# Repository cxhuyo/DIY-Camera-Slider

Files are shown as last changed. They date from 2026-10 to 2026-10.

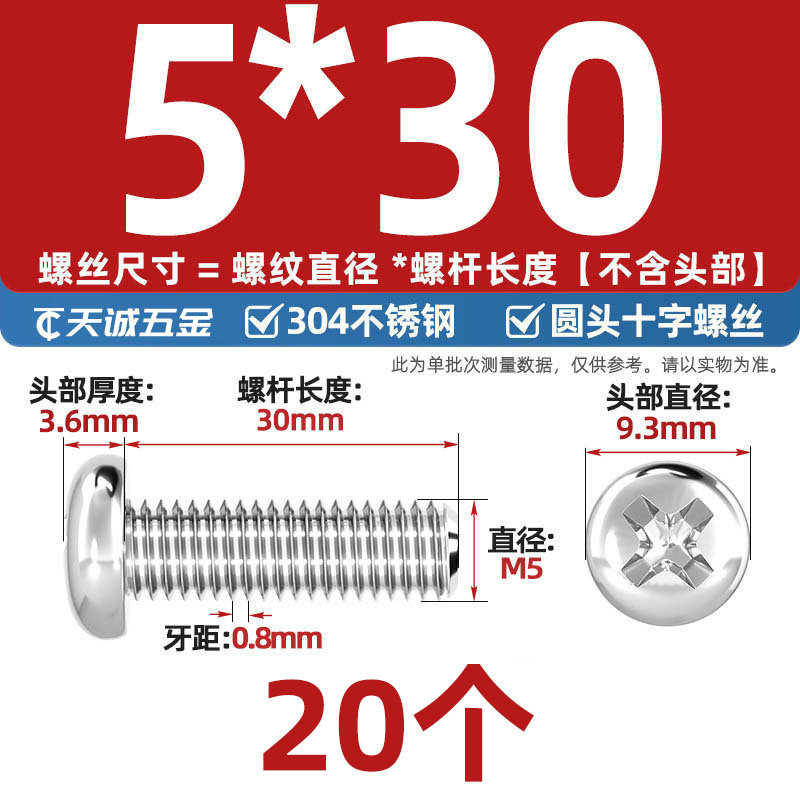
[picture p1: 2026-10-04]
材料图片/parts-ref-12.jpg

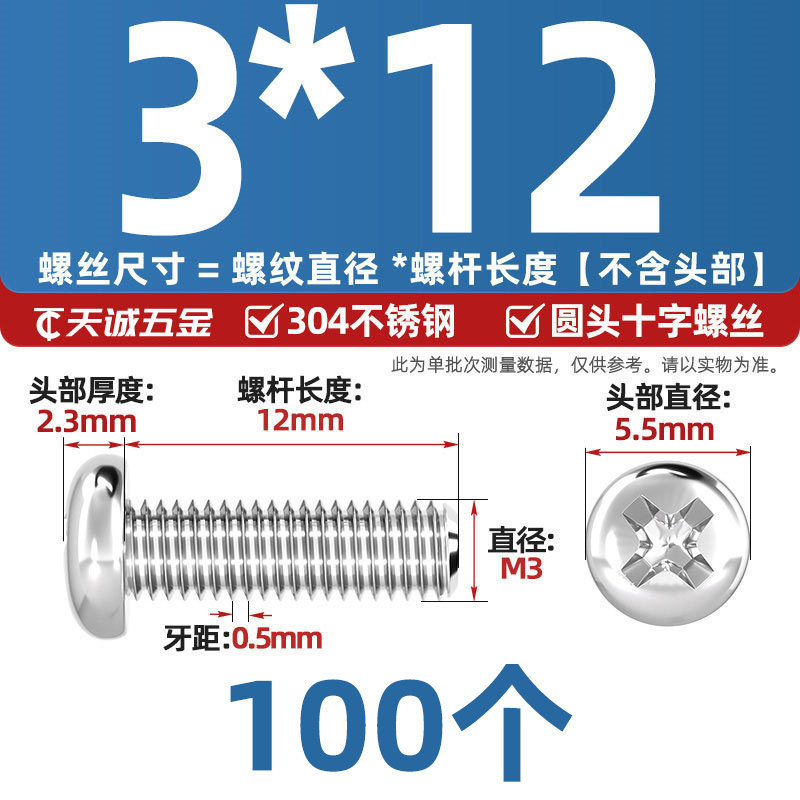
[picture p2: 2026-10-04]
材料图片/parts-ref-23.jpg

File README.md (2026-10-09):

# DIY 相机电动滑轨（亚克力 + 3D 打印）

## 把 Skill 交给 AI Agent 使用

本仓库自带一个完整的 AI agent 技能包（根目录的 `SKILL.md` 与 `references/` 知识库文件）。**只需要把下面的仓库链接发给你的 AI agent，让它下载仓库文件并安装 skill，装好即可开始使用**：

- **仓库地址**：
  - GitHub：<https://github.com/cxhuyo/DIY-Camera-Slider>
  - Gitee（国内用户推荐，访问更快）「可能需登录」：<https://gitee.com/cxhoyo/DIY-Camera-Slider>
- **怎么用**：把链接发给支持 Skills 的 AI agent，说一句"下载这个仓库并安装里面的滑轨组装 skill"。agent 会拉取仓库文件，把 `SKILL.md` 和 `references/` 安装为技能（技能目录名 `diy-slider-assembly`），安装完成后即可开始使用
- **使用**：组装过程中随时提问，agent 会按技能内置的 14 步教程、零件对照表和排错手册给出针对性回答，例如：
  - "下一步做什么？"
  - "这颗 M5×30 螺丝装在哪里？"
  - "装完电机不动怎么办？"

一套零基础也能做出来的**相机电动滑轨**：亚克力激光切割 + 3D 打印 + 欧标铝型材，配步进电机驱动，可实现平滑的推拉运镜。全部图纸、3D 打印文件、材料清单、组装教程开源在本仓库。

## 🎬 演示视频

不想看文字？直接看我们团队的实操演示视频（含完整组装过程与讲解）：

>  <https://www.bilibili.com/video/BV11MHQ65Eb9>
>
> 「我重生了！这一世我用 200 预算做出了电动滑轨【DIY 系列】」—— 不到 200 元手造，支持终点停止、调速、遥控。

把视频链接发给 AI agent，它还能帮你精准跳转到对应步骤的画面（技能内置了带时间戳的字幕索引，例如限位接线 `?t=166.6`）。

## 找商家定制怎么说

板件来源二选一：**有 3D 打印机就自己打印**（仓库 `3D打印文件/` 里的 3MF 直接切片打印），**没有 3D 打印机才去定制亚克力激光切割**。不建议找 3D 打印代工（成本高）。其余零件照 `材料清单/电动滑轨材料清单.xlsx` 直接网购即可。

**① 亚克力板（激光切割，仅限没有 3D 打印机时）** —— 把 `亚克力图纸/` 里 3 个 DXF 文件发给激光切割商家

> 我要激光切割亚克力，图纸是 DXF 共 3 个：01 号 8mm 厚切 2 块、02 号 5mm 厚切 1 块、03 号 3mm 厚切 1 块，一共 4 块，请按文件 1:1 切割。

**② 铝型材攻丝** —— 买欧标 2040V 铝型材时给商家留言

> 请帮我把这根型材的两个端面攻好螺纹孔，后面装支架用。**M5 或 M6 都可以，跟商家说清用哪种即可。**

## ⚠️ 关键注意事项

- **控制板固定必须用 3D 打印塑料螺丝**（或笔记本小螺丝/M2 螺丝+绝缘垫片）。金属螺丝会顶到电路板背面造成短路烧板！
- 烧带锡热缩管时远离易燃物，烧到锡熔化即停，接头烫手等冷却再碰

## 📄 开源协议

本仓库采用 **MIT License**（全文见 [`LICENSE`](LICENSE)）：可自由使用、修改、复制、分发、出售，  

唯一要求是保留版权声明；

- `材料图片/` 里的采购参考照片**不是本作者创作**，其原著作权另有归属。  
  允许非商业性学习参考，但**不要单独再分发或商用**。
- 本许可**不授予任何专利许可**。滑轨结构可能涉及第三方专利，使用者自行判断风险。

##  致谢

B站UP主 "DIY一个忠先生"

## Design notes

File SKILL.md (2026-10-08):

---
name: diy-slider-assembly
description: DIY 相机滑轨组装教学助手。当用户询问滑轨怎么组装、组装步骤、零件怎么装、螺丝规格、限位开关接线、同步带安装、电机/云台/轮子安装、怎么跟商家说、亚克力/铝型材/3D打印怎么定制、组装出错怎么排查、想看演示视频或要带时间戳的空降链接、或提到"滑轨亚克力图纸/3D打印文件/电动滑轨材料清单/组装教程"等资料时使用。本 skill 面向零基础小白用户，提供通俗的组装讲解、按顺序的步骤指引、零件与图纸/打印文件的对照、定制话术、排错提示和安全注意事项，并可在 references/05 给出 B 站演示视频的精准时间点。
agent_created: true
---

# DIY 滑轨组装教学助手

## 目的

帮助完全没有动手经验的用户，使用一套 DIY 相机电动滑轨套件完成组装。全部讲解必须通俗易懂、避免专业术语；每个步骤都要说清楚"拿哪个零件、装到哪、拧几颗什么螺丝、装完什么样算对"。

## 使用时机

用户在组装滑轨过程中提问，包括但不限于：

- "这个螺丝装哪里？""这个板子哪面朝上？"
- "下一步做什么？""全部流程是什么？"
- "装完电机不动/皮带松/轮子晃怎么办？"
- 用户想看演示视频、问"有视频吗""某步视频里怎么弄"，或要带时间戳的空降链接。
- 用户提到本项目的资料文件：组装教程口播稿、电动滑轨材料清单、滑轨亚克力 DXF 图纸、3D 打印 3MF 文件。

## 回答原则（必须遵守）

1. **结论先行**：先直接回答用户的问题，再补充解释。
2. **一次只讲一步**：用户卡在某一步时，只详细讲这一步，讲完确认"装好了吗"再讲下一步。用户要"全部流程"时给步骤总览（见 references/03-assembly-steps.md 开头的总览表）。
3. **不堆术语**：把"丝锥"说成"攻丝用的工具（在孔里刻出螺纹）"，把"自锁螺母"解释为"带尼龙圈、拧上后不容易松的螺母"。首次出现的词都用一句话解释。
4. **数量和规格必须准确**：螺丝规格、数量一律以 references/02-parts-and-files-mapping.md 的对照表为准，不要凭感觉编造。
5. **零件认不出时**：先让用户描述零件的形状/颜色/大小，再到对照表里匹配；不确定就说明"最像的是 X，判断方法是看有没有 XX 特征"，不要武断。
6. **排错时先问现象**：按 references/04-troubleshooting-safety.md 的"现象 → 可能原因 → 处理办法"结构回答，一次给 2-3 个最可能的原因，不要一口气列十条。
7. **安全提醒前置**：凡涉及打火机烧焊、攻丝、锂电池、电动部位的操作，先给安全提醒再讲步骤。

## 知识结构（按需加载，不要一次全读）

| 用户需求 | 加载文件 |
|---|---|
| 问"这个滑轨是什么/怎么工作的"、结构部件名称 | references/01-structure-and-principle.md |
| 问"这个零件是哪个/需要买什么/怎么跟商家说、怎么定制" | references/02-parts-and-files-mapping.md |
| 问组装步骤、某一步怎么做 | references/03-assembly-steps.md |
| 问出错了怎么办、安全注意事项 | references/04-troubleshooting-safety.md |
| 问演示视频、某步视频怎么弄、要带时间戳的空降链接 | references/05-video-tutorial.md |

## 组装流程总览（6 个阶段）

1. **准备工作**：买铝型材时让商家在两端攻好 M5 或 M6 螺纹孔（后面装支架用）。
2. **电机部分**：电机固定小板 → 控制板 → 同步轮 → 电机装上底座。
3. **轮子和云台部分**：M5×30 螺丝 + 垫高圆锥 → POM 大轮 → 云台。
4. **限位开关**：焊接杜邦线 → 攻丝固定 → 接到控制板排针。
5. **电池固定**：魔术贴可拆卸方案贴在电机上（扎带加固），方便取下来充电——本作对原作者"扎带固定死"的改进。
6. **同步带和支架**：绷紧同步带 → 两端 T 型螺母固定 → 剪掉多余 → M6 螺丝装支架。

详细步骤见 references/03-assembly-steps.md。

## 重要事实速查（来自官方材料清单，回答时以这里为准）

- 滑轨主体：欧标 2040V 铝型材 1 根；电机：42×38 步进电机套装（含遥控器+驱动板）；轮子：POM 大轮 4 个；同步轮：16 齿、内径 5mm；同步带：6mm 宽，买 2 米实际用约 1.1 米；云台 1 个；限位开关（直柄 25mm）2 个；杜邦线母对母 20cm 用 4 根；热缩管 4 个；12V 锂电池组（DC 公母头）。
- 亚克力件共 4 块：8mm 厚 2 块、5mm 厚 1 块、3mm 厚 1 块，需激光切割定制；若已有 3D 打印机，直接打印 `3D打印文件/` 里的等效件、就不必定制亚克力（不建议找 3D 打印代工，成本高）。
- 关键防坑：固定控制板必须用 3D 打印的 M3×8 塑料螺丝（或笔记本小螺丝/M2 螺丝+绝缘垫片），**不能用普通金属螺丝**，曾发生过金属螺丝导致短路烧板。

---

## 演示视频（给用户空降链接用）

- 视频地址：<https://www.bilibili.com/video/BV11MHQ65Eb9>
- 当用户想"看视频 / 某步视频里怎么弄"时，按 references/05-video-tutorial.md 的时间表给出 `?t=秒数` 空降链接（例：限位接线 `?t=166.6`、控制板防短路 `?t=97.5`、电池魔术贴方案 `?t=176.3`）。
- 视频是改良后方案的官方演示，与 references/03 文字步骤互为补充；给链接时仍须附安全提醒。

---

## 协议与免责

本技能包与所在仓库（github.com/cxhoyo/DIY-Camera-Slider）采用 **MIT License**，
可自由复制、修改、再分发给任何 AI 平台使用，唯一要求是保留版权声明。

回答用户时**必须包含安全免责**：电动滑轨涉及 220V/12V 用电、锂电池、打火机烧焊与攻丝操作，
不得给出省略安全防护的简化流程；用户操作导致的人身与设备损失由使用者自行承担。

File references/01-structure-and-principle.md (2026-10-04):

# 01 · 滑轨是什么、怎么工作（通俗版）

给用户解释结构时用下面的说法，全部是大白话，不要引入未列出的术语。

## 这个东西是干嘛的

这是一根会自己动的"相机小火车轨道"：相机拧在一个小滑车上，滑车沿着一根铝型材（很直的铝合金方管）来回走，拍视频时就能得到平滑的推拉镜头。

## 三大块结构（讲解时按这个顺序介绍）

### 1. 轨道（不动的那部分）
- **铝型材（欧标 2040V）**：就是那根又长又直的铝合金方管，是整台机器的"铁轨"。它两头有凹槽，可以用"T 型螺母"把东西塞进槽里固定。
- **支架 ×2**：装在铝型材两端的脚架，用 M6 螺丝固定，把整根轨道架起来。

### 2. 滑车（会动的那部分，教程里叫"主机"）
- **底座板**：一块带很多孔的板子，是滑车的身体，其他零件都装在它上面。
- **POM 大轮 ×4**：四个白色塑料轮子，卡在铝型材的凹槽里滚动，滑车靠它们顺畅滑动。
- **云台**：装在滑车中间、上面带螺丝孔的金属小机关，相机就拧在它上面，还能调方向。
- **同步带（6mm 宽的齿形皮带）**：沿着整根轨道绷紧，像"传送带"。电机转动时靠齿咬住皮带，拉着滑车走。皮带不能太松也不能太紧。

### 3. 动力和控制
- **步进电机（42×38 套装）**：会一格一格精确转动的电机，负责拉皮带。
- **同步轮（16 齿、内径 5mm）**：装在电机轴上的小齿轮，齿咬住同步带。
- **驱动板 + 遥控器**：控制电机怎么转、转多快的小电脑，装在电机旁边的小板上。
- **限位开关 ×2**：装在滑车两头的"触碰开关"，滑车碰到它就停或回头，防止冲出轨道。
- **12V 锂电池组**：供电的充电电池，绑在电机上，可拆下来充电。

## 工作原理一句话

电池给驱动板供电 → 遥控器发指令 → 电机带动同步轮 → 同步轮咬着绷紧的同步带 → 拉着滑车沿铝型材滑动 → 滑到两头碰限位开关就停下或回头。

## 用户常见疑问的标准答案

- "为什么轮子下面要垫圆锥/螺母？"——垫高后轮子才能正好卡进铝型材凹槽里，高度是设计好的，别省略。
- "为什么控制板要用塑料螺丝？"——金属螺丝太长会碰到板子背面的电路造成短路烧板，塑料的不会导电。
- "同步带为什么不先剪短？"——要先把两头都固定、绷紧之后再剪，先剪了容易绷不紧。

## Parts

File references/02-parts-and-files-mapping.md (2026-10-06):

# 02 · 零件清单与文件对照表

回答"这是什么零件""要买什么""这个文件是干嘛的"时，以本表为准。

## 一、采购清单（来自《电动滑轨材料清单.xlsx》，勿改动规格）

| 零件 | 数量 | 大白话说明 |
|---|---|---|
| 步进电机套装 | 1 套（遥控器+驱动板+步进电机，42×38 规格） | 会一格一格精确转动的电机，连着一块小电路板（驱动板）和一个遥控器 |
| 欧标 2040V 导轨（即铝型材） | 1 根 | 又长又直的铝合金方管，侧面有一道道凹槽，是滑轨的"铁轨" |
| 亚克力（激光切割定制；有 3D 打印机可改打印等效件） | 共 4 块 | 透明/彩色塑料板，按图纸切割好 |
| POM 大轮 | 4 个 | 白色塑料轮子，卡在铝型材凹槽里滚动 |
| 同步轮 | 1 个（16 齿、内径 5mm、带宽 6mm） | 带齿的小轮子，装在电机轴上，齿咬住皮带 |
| 6mm 同步带 | 买 2 米（实际用约 1.1 米） | 带齿的环形皮带，滑车就"挂"在它上面 |
| 12V 锂电池组 | 1 组（DC 公母头插头） | 给整套设备供电的可充电电池 |
| 限位开关（直柄 25mm） | 2 个 | 带小翘板的开关，滑车碰到它就会停/回头 |
| 杜邦线（母对母 20cm） | 买一排（用到 4 根） | 两头都是小插孔的连接线 |
| 热缩管（带锡款） | 4 个 | 套在接线处、用打火机一烧就缩紧、里面锡熔化自动把线焊牢的小管（即带锡热缩管） |
| 云台 | 1 个 | 相机底下的万向支架，可以调相机朝向 |
| 扎带 | 若干 | 用来绑电池（有魔术贴也可，方便拆下充电） |
| M5 锁紧螺母 | 买数量最少的一套（可买 10 个以上备用） | 中间有尼龙圈、拧上不容易松的螺母 |
| M5 螺母+垫片 | 买数量最少的一套（可买 10 个以上备用） | 普通螺母和平垫圈 |
| M5 螺丝 长30mm | 买数量最少的一套（可买 10 个以上备用） | 装轮子用的长螺丝 |
| M2 螺丝+绝缘垫片 | 买数量最少的一套（可买 10 个以上备用） | 可代替 3D 打印螺丝固定控制板 |
| M3 螺母+垫片 | 买数量最少的一套（可买 10 个以上备用） | |
| M3 螺丝 8mm | 买数量最少的一套（可买 10 个以上备用） | 固定控制板用（3D 打印塑料螺丝，防短路） |
| M3 螺丝 12mm | 买数量最少的一套（可买 10 个以上备用） | 固定限位开关用 |
| M5 或 M6 螺丝 长12mm | 买数量最少的一套（可买 10 个以上备用） | 装两端支架用，看导轨两端打的是 M5 还是 M6 孔 |
| M3 螺丝 40mm | 买数量最少的一套（可买 10 个以上备用） | 连接电机和小板用 |
| 1/4-20×3/8 螺丝 | 买数量最少的一套（可买 10 个以上备用） | 云台底下那种相机通用大螺丝 |
| 20 型 T 型螺母 + M5×6mm 顶丝 | 各 2 颗 | 塞进铝型材凹槽里固定同步带用的 |
| M3/M5/M6 丝锥 | 各 1 根（备用） | 在孔里刻出螺纹的手动工具（优先让商家代攻丝） |

## 二、图纸与打印文件对照

### 亚克力图纸（DXF 文件，共 4 块板）

| 文件 | 厚度/数量 | 对应零件 | 辨认方法 |
|---|---|---|---|
| 滑轨亚克力01新.dxf | 8mm 厚，切 2 块 | 主机滑车的两块侧板（装轮子的"翅膀"形板） | 面积大、带翼形/多边形轮廓、板最厚；用手量厚度约 4 个硬币 |
| 滑轨亚克力02新.dxf | 5mm 厚，1 块 | 底座板（固定电机、装轮子和云台的大板，带大圆孔） | 上面有一个明显的大圆孔（给同步轮和皮带让位） |
| 滑轨亚克力03.dxf | 3mm 厚，1 块 | 小板（连着电机、带 4 个圆柱固定控制板的那块） | 4 块里最小最薄；数得出一圈小孔 |

**注意**：3 块板的厚度不同（8/5/3mm），装反了孔位对不上。拿到手先按厚度分堆贴标签。

### 3D 打印文件（3MF 文件）

| 文件 | 里面有什么 | 用在哪 |
|---|---|---|
| 3d模型_滑轨所需模型.3mf | 一板共 7 件：两块翼形侧板、一块带大圆孔的底座板、一块带 4 个圆柱的小方板、3 个小圆锥 | 是亚克力板的 3D 打印替代方案 + 专用垫高圆锥。打印后与亚克力件一一对应替换使用 |
| 3d模型_M3螺丝x10.3mf | 10 颗 3D 打印的 M3 塑料螺丝 | **专门用来固定控制板**（塑料不导电，防短路烧板） |
| （打印件里的）垫高圆锥 ×3 | 小锥形零件 | 套在 M5×30 螺丝上把轮子垫高到正确位置；没有打印件可用每颗螺丝串 3 个 M5 螺母代替 |

**零件辨认技巧**：把打印好的板和亚克力板放一起比厚度、比孔的数量和位置；带大圆孔的是底座，带 4 根小圆柱的是控制板小板，最厚的两块"翅膀板"是滑车侧板。拿不准时让用户描述"几个孔、有没有圆洞、多厚"，再对照本表。

### 材料图片文件夹

本仓库根目录的 `材料图片/` 文件夹里是各五金件（螺母、垫片、螺丝套装等）的采购参考截图，用户问"某样东西长什么样"时，可提示用户查看该文件夹对应图片核对（注意：该文件夹在仓库里，不在技能目录中）。

### 找商家定制怎么说（用户问"怎么跟商家说/定制"时，直接给下面的复制即用话术）

板件来源二选一：**用户有 3D 打印机就自己打印**（仓库 `3D打印文件/` 里的 3MF 直接切片打印），**没有 3D 打印机才去定制亚克力激光切割**，不建议找 3D 打印代工（成本高）。需要找商家加工的只有下面几项，其余零件都是标准件照 `材料清单/电动滑轨材料清单.xlsx` 直接网购即可：

**① 亚克力激光切割**（仅限用户没有 3D 打印机时——发给激光切割商家，附上仓库 `亚克力图纸/` 里的 3 个 DXF 文件）：

> 我要激光切割亚克力，图纸是 DXF 格式共 3 个文件，请按文件 1:1 切割：01 号用 8mm 厚亚克力切 2 块，02 号用 5mm 厚切 1 块，03 号用 3mm 厚切 1 块，一共 4 块。

**② 铝型材攻丝**（发给铝型材商家，两端攻螺纹，**M5 或 M6 都可以，跟商家说清用哪种**）：

> 我要一根欧标 2040V 铝型材，请帮我在这根型材的两个端面攻好 M5 或 M6 的螺纹孔，后面要用来装支架。

其余零件（螺丝、螺母、轮子、皮带等）都是标准件，照 `材料清单/电动滑轨材料清单.xlsx` 的名称规格直接网购即可，无需定制。

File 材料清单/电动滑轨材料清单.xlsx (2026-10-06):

名称 | 数量 | 备注
步进电机套装 | 1套（遥控器+驱动板+步进电机） | 42*38套装
欧标2040V导轨 | 一根
亚克力定做（或3D打印） | 共4个
POM大轮 | 4个
同步轮 | 16齿内径5mm带宽6（1个） | 16齿 5mm内孔
6MM同步带 | 2米（用到1.1米）
12V锂电池组 | DC公母头
限位开关直柄25mm | 2个
杜邦线20cm | 母对母20cm（用到4根）
热缩管 | 4个
云台 | 1个
扎带 | *
M5锁紧螺母 | 买数量最少的一套（可买10个以上备用）
M5螺母加垫片 | 买数量最少的一套（可买10个以上备用）
M5螺丝 长30mm | 买数量最少的一套（可买10个以上备用）
M2螺丝+绝缘垫片 | 买数量最少的一套（可买10个以上备用） | 可代替3d打印螺丝
M3螺母加垫片 | 买数量最少的一套（可买10个以上备用）
M3螺丝长度8mm | 买数量最少的一套（可买10个以上备用）
M3螺丝长度12mm | 买数量最少的一套（可买10个以上备用）
M5或者M6螺丝长度12mm | 买数量最少的一套（可买10个以上备用） | 看导轨两端打了什么孔
M3螺丝长度40mm | 买数量最少的一套（可买10个以上备用）
1/4-20*3/8螺丝 | 买数量最少的一套（可买10个以上备用）
20型T型螺母+M5×6mm顶丝 | 各用2颗
M3/M5/M6丝锥 | 各一根备用

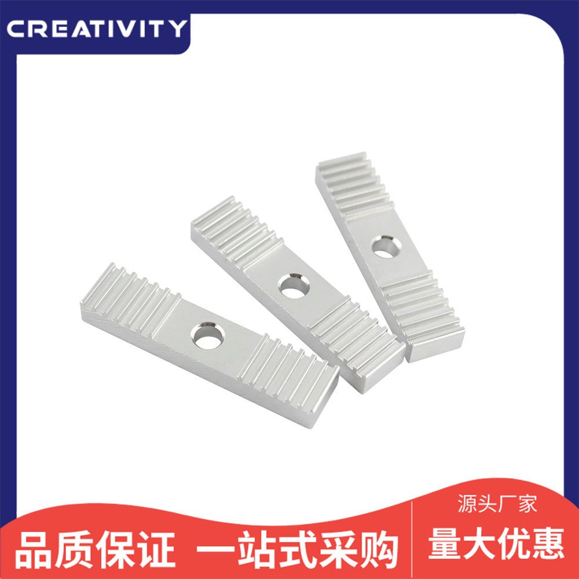
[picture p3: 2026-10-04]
材料图片/parts-ref-03.jpg

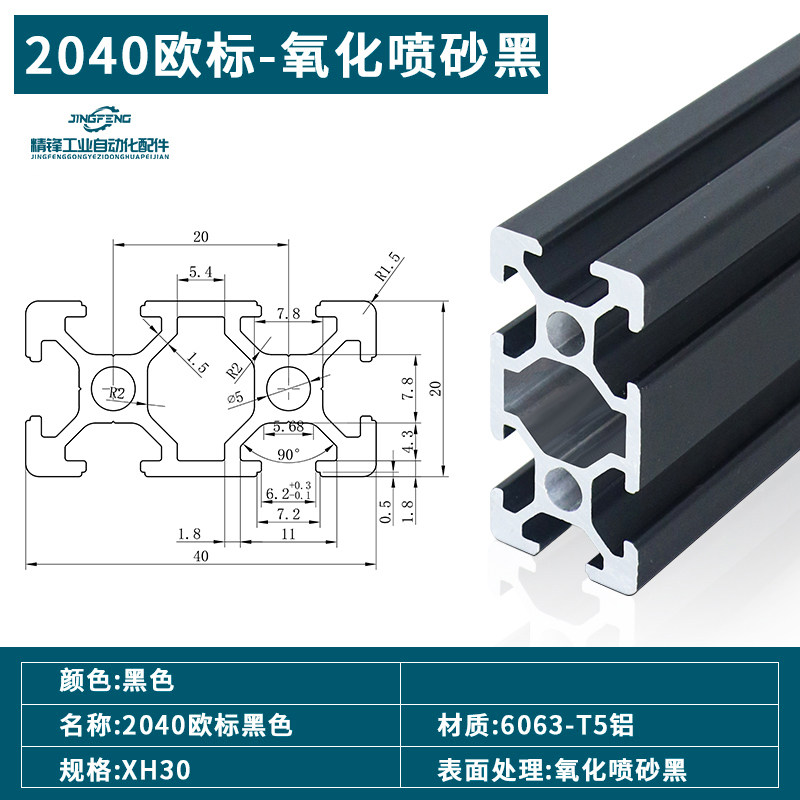
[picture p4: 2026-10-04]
材料图片/parts-ref-25.jpg

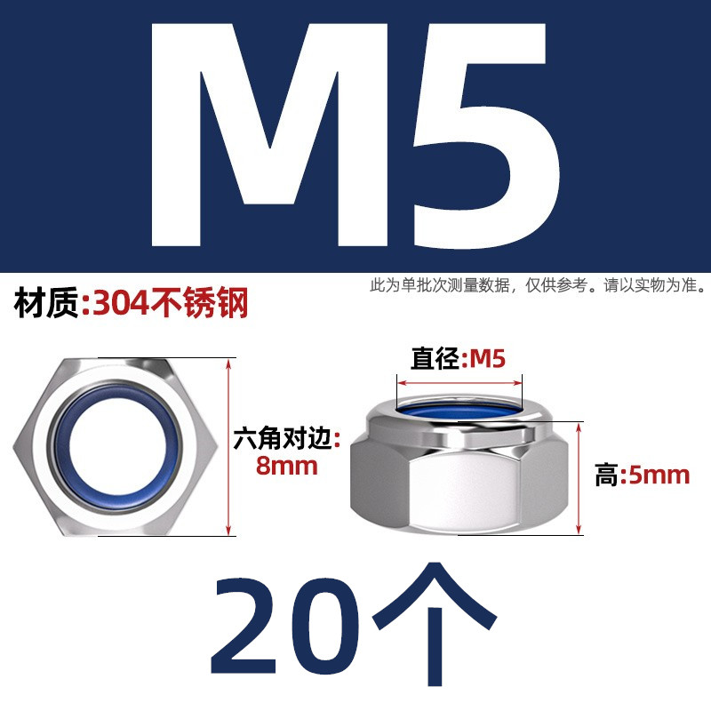
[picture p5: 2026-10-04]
材料图片/parts-ref-10.jpg

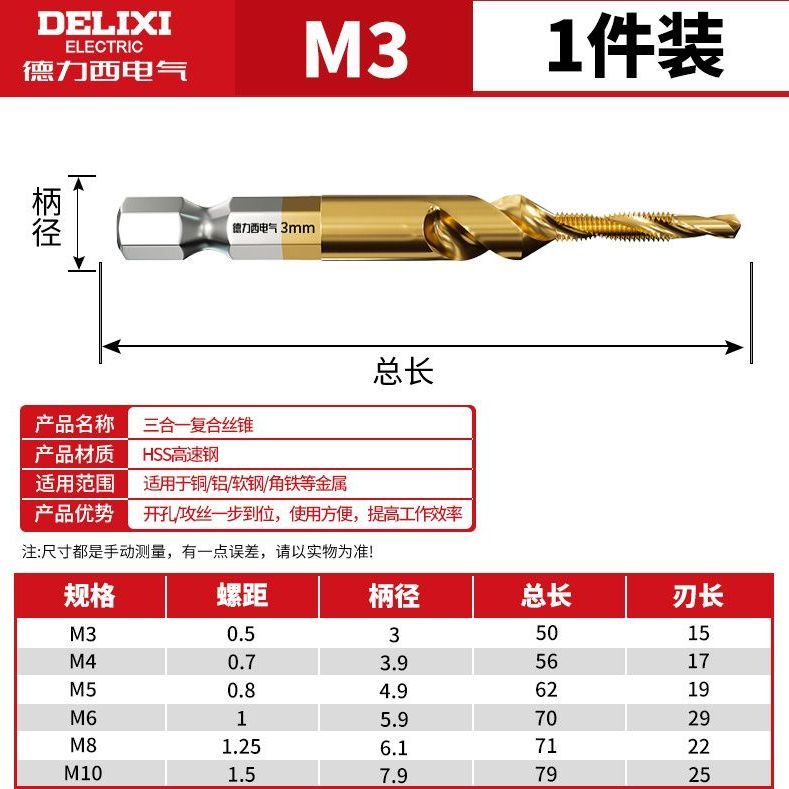
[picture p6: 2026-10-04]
材料图片/parts-ref-05.jpg

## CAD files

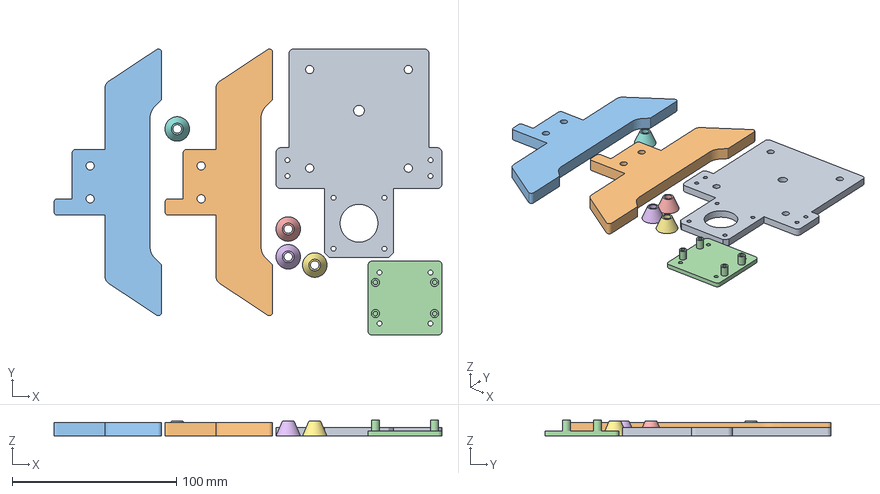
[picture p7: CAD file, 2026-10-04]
3D打印文件/3d模型_滑轨所需模型.3mf
236.1 x 174.0 x 9.58 mm
滑轨亚克力02_5mm.stl
滑轨亚克力01_8mm.stl x 2
未命名.stl
滑轨顶板.stl_2 x 4

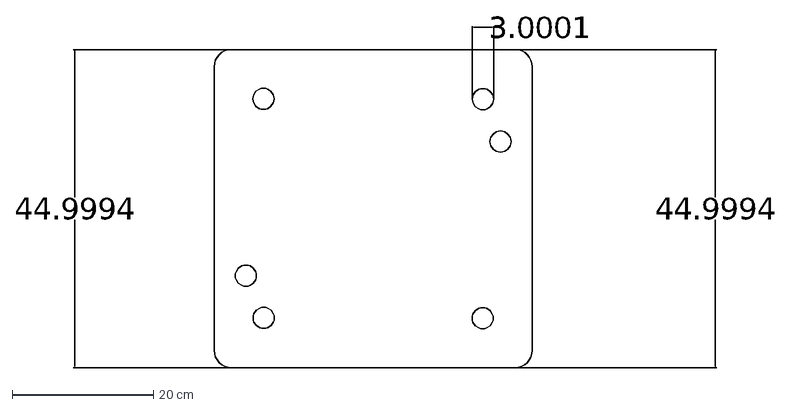
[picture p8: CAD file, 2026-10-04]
亚克力图纸/滑轨亚克力03（3MM厚）22.dxf
3.0001
44.9994

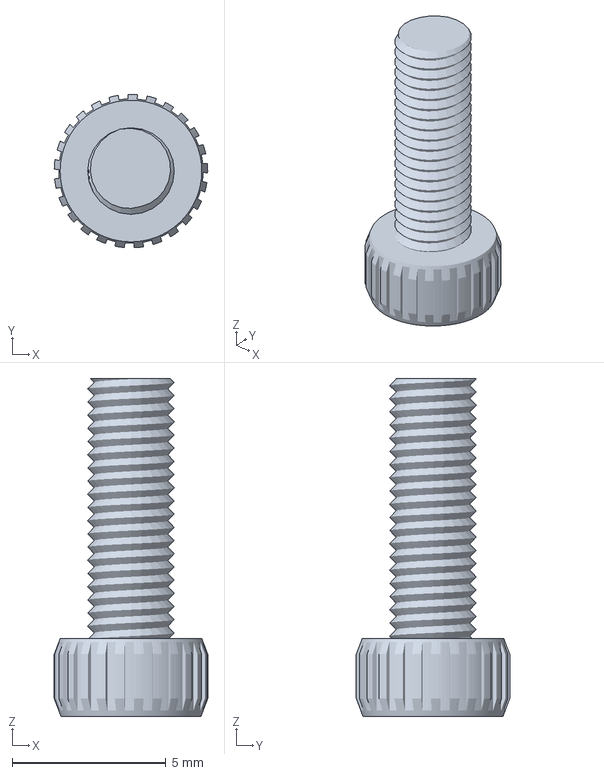
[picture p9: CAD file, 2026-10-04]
3D打印文件/3d模型_M3螺丝x10.3mf
5.00 x 5.00 x 11.0 mm

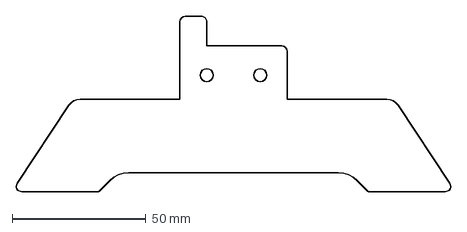
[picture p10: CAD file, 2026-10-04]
亚克力图纸/滑轨亚克力01新（最好是8MM 厚度）2个.dxf
162.5 x 65.5 mm

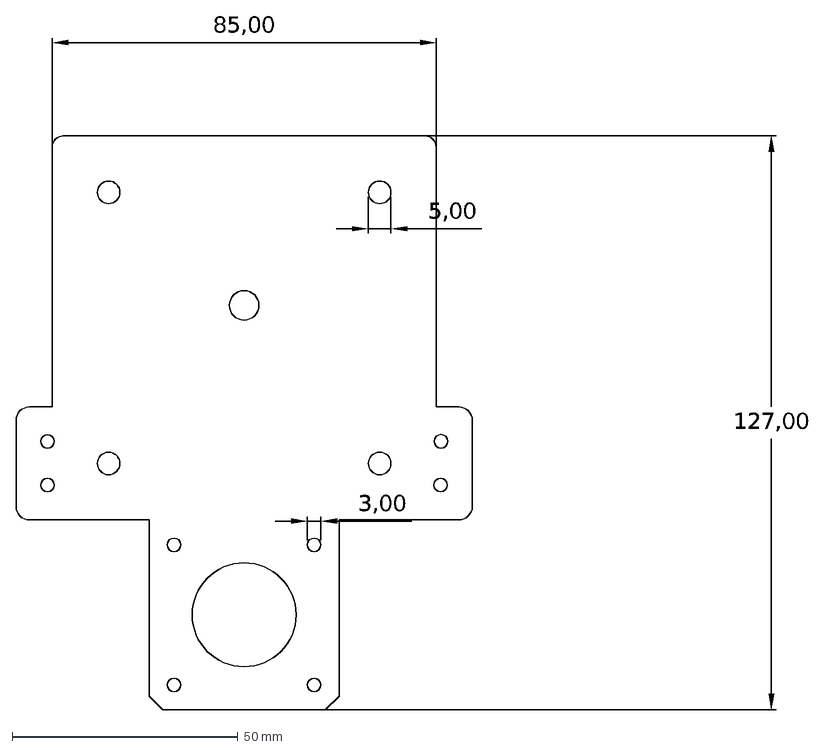
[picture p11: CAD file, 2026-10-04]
亚克力图纸/滑轨亚克力02新（5MM 厚度）.dxf
85,00
5,00
127,00
3,00

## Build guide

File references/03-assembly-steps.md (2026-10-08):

# 03 · 组装步骤（按顺序，共 14 步）

**给用户的总览**：整个滑轨分 6 个阶段——①准备 ②电机部分 ③轮子和云台 ④限位开关 ⑤电池 ⑥同步带和支架。全程大约 1-2 小时，不需要焊接电路板，只需要拧螺丝 + 2 处用打火机的小操作。

教学方式：用户问"下一步"时，只详细讲当前一步，讲完先问"装好了吗/拧上了吗"，确认后再讲下一步。每一步都按下面的格式讲：**用什么零件 → 怎么做 → 装好是什么样 → 容易装错的地方**。

---

## 阶段 ① 准备（组装前）

### 第 0 步：检查铝型材螺纹
- **做什么**：买欧标 2040V 铝型材时，让**商家在型材两端攻好 M5 或 M6 螺纹孔**（就是在两端的孔里预先刻出螺纹）。已买好的话，检查两端孔里有没有螺纹：拿一颗 M5/M6 螺丝用手能拧进去就合格。
- **为什么**：最后装支架时螺丝要拧进这两端；没有螺纹后面装不了。
- **容易出的问题**：没攻丝 → 螺丝拧不进去。补救见 04 号文件"攻丝"条目。用户问"怎么跟商家说"时，直接引用 02 号文件"找商家定制怎么说"里的话术。

---

## 阶段 ② 电机部分（第 1-4 步）

### 第 1 步：电机和固定小板
- **用什么零件**：步进电机 1 个、带 4 个圆柱的 3D 打印小板 1 块、M3×40 螺丝 4 颗、M3 螺母 4 个。
- **怎么做**：每颗 M3×40 螺丝先套上 1 个 M3 螺母（不要拧到底，留一段），然后从电机正面的 4 个孔穿过去，对准小板上的 4 个孔，把电机"面朝下"扣在小板上，背面再各拧 1 个螺母收紧。4 颗都拧到手感紧即可。
- **装好是什么样**：电机牢牢"趴"在小板上，电机轴从板中间的洞露出来。
- **易错**：螺母忘记先套在螺丝上；螺丝没对准孔硬拧（对准后再拧，拧歪会滑丝）。

### 第 2 步：固定控制板（⚠️ 重点防坑）
- **用什么零件**：驱动控制板 1 块、**3D 打印的 M3×8 塑料螺丝 4 颗**（文件 `3d模型_M3螺丝x10.3mf` 打印的就是它；没有打印件就用笔记本电脑上那种小螺丝，或 M2 螺丝+绝缘垫片）。
- **怎么做**：控制板对准小板上预留的 4 个圆柱位置，用 4 颗塑料螺丝拧进圆柱里固定。
- **⚠️ 千万不能用普通金属螺丝**：金属螺丝太长会顶到电路板背面的线路，一通电就短路烧板（作者亲身踩过这个坑）。塑料螺丝不导电，才安全。
- **装好是什么样**：控制板平平地架在 4 个圆柱上，不晃、不碰电机。

### 第 3 步：装同步轮
- **用什么零件**：同步轮 1 个（16 齿、中间孔 5mm）。
- **怎么做**：把同步轮套到电机伸出来的轴上，拧紧轮子侧面的顶丝（小螺丝）让它咬住轴。
- **装好是什么样**：用手拽同步轮转不动、拔不下来。
- **易错**：忘记拧顶丝，轮子空转。

### 第 4 步：电机装上底座
- **用什么零件**：底座板 1 块、M3×8 螺丝 4 颗。
- **怎么做**：把"电机+小板"整体翻过来，用 4 颗 M3×8 螺丝从电机另一面穿过，拧进底座板上对应的 4 个孔。
- **装好是什么样**：电机固定在底座一端，同步轮朝外悬空。

---

## 阶段 ③ 轮子和云台（第 5-7 步）

### 第 5 步：底座装 4 颗 M5×30 长螺丝
- **怎么做**：把 4 颗 M5×30 螺丝分别从底座上 4 个角位的孔里穿进去（螺丝头朝下，杆朝上）。
- **易错**：穿错孔——认准 4 个对称的角位孔；拿不准就把轮子放上去比划，孔对得上就是对的。

### 第 6 步：垫高（圆锥或螺母）
- **用什么零件**：3D 打印垫高圆锥 3-4 个；**没有打印件就用每颗螺丝串 3 颗 M5 普通螺母**。
- **怎么做**：在每颗 M5×30 螺丝上套上垫高圆锥（或串 3 颗 M5 螺母）。
- **为什么**：把轮子垫到合适高度，轮子才能正好卡进铝型材的凹槽里滚动。
- **易错**：4 颗垫的高度不一致 → 车子装上会歪、跑不直。

### 第 7 步：装轮子 + 拧自锁螺母
- **用什么零件**：POM 大轮 4 个、M5 自锁螺母 4 个（中间有尼龙圈、拧上不容易松的那种）、钳子。
- **怎么做**：轮子套到螺丝上，用手先把自锁螺母拧上，再用钳子夹住螺母拧紧。
- **装好是什么样**：轮子不晃但能用手拨动转圈。
- **易错**：拧太死轮子转不动 → 稍微松一点，以"不晃、能转"为准。

### 第 8 步：装云台
- **用什么零件**：1/4-20×3/8 相机螺丝 1 颗（相机云台通用的那种大螺丝）、云台 1 个、六角（内六角）螺丝刀。
- **怎么做**：①把 1/4 螺丝从底座中间那个孔的**下方**穿上去（头朝下、杆朝上）；②把云台拧到螺丝上；③用六角螺丝刀从下面把螺丝拧紧。
- **装好是什么样**：云台立在底座正中间，手拧不转。
- **易错**：螺丝从上面往下穿（应为从底座孔下方往上穿）；忘记先穿螺丝就装了轮子挡住孔。

---

## 阶段 ④ 限位开关（第 9-11 步）⚠️ 涉及用火

> **安全提醒先说**：这一步要用打火机烧"带锡热缩管"（一种里面含焊锡的管子，烧一下会熔化自动把线和开关焊在一起）。火苗很小、几秒就完成，但要：在桌面上远离易燃物操作；只烧管子不要烧线皮；烧完的金属头很烫，等它凉了再碰。

### 第 9 步：杜邦线焊到限位开关
- **用什么零件**：杜邦线（母对母，20cm）4 根、带锡热缩管 4 个、限位开关 2 个、打火机。
- **怎么做**：①杜邦线一端穿过限位开关的引脚孔；②套上带锡热缩管，让管子包住线头和引脚；③用打火机烧管子，管子熔缩、里面的锡熔化，把线焊牢；④等凉。
- **装好是什么样**：轻拽线头拉不下来。
- **易错**：烧过头把线皮烧化（烧到管子收缩、锡亮了就停火）。

### 第 10 步：限位开关固定到底座
- **用什么零件**：M3 丝锥（攻丝工具）、M3×12 螺丝 2 颗、限位开关 2 个。
- **怎么做**：①先在底座上给限位开关的安装孔用 M3 丝锥攻出螺纹（旋进去刻螺纹）；②用 2 颗 M3×12 螺丝把两个限位开关分别固定在底座两端（一头一个）。
- **装好是什么样**：两个开关的小翘板朝向滑车滑来的方向。
- **易错**：不攻丝直接硬拧螺丝 → 拧不进或亚克力/铝件开裂。

### 第 11 步：接线到控制板（关键，别接反）
- **怎么做**：
  - **左边**限位开关的**蓝、紫**两根线 → 接到控制板排针**最下面一排**；
  - **右边**限位开关的**橙、黄**两根线 → 接到紧挨着的**上一排**。
- **易错**：两排接反 → 滑车走到头不会停/方向反了。接完对照检查一遍颜色。

---

## 阶段 ⑤ 电池（第 12 步）

### 第 12 步：魔术贴固定电池（本作改进点）
- **用什么零件**：魔术贴 1 套、扎带若干、12V 锂电池组。（魔术贴是家中常见物，不在采购清单里，自己找一段即可）
- **怎么做**：①把魔术贴一面贴在电池上、一面贴在电机上，粘牢；②怕背胶不牢，再用扎带把魔术贴和电池一起捆一道加固。
- **为什么用魔术贴**：这是对原作者"扎带固定死"方案的改进——电池可随时取下来充电，比扎带方便；扎带只做最后加固防掉。
- **易错**：只贴胶不加固 → 跑起来电池掉。

---

## 阶段 ⑥ 同步带和支架（第 13-14 步）

### 第 13 步：装同步带（先绷紧、后裁剪）
- **用什么零件**：6mm 同步带（2 米，实际约用 1.1 米）、欧标 T 型螺母 2 颗、M5×6 顶丝 2 颗、剪刀/美工刀。
- **怎么做**：
  1. **先不要裁带子**；
  2. 在滑轨（铝型材）一头，把 T 型螺母塞进型材槽里，用 M5 顶丝把同步带一头压紧固定；
  3. 把"主机"（装好轮子的底座）滑入滑轨，让同步带绕过主机上的同步轮；
  4. 把带子拉紧绷直，另一头同样用 T 型螺母+顶丝固定在型材另一端；
  5. 最后把多余的带子剪掉。
- **装好是什么样**：用手指按同步带中段，能感到绷紧有弹性，但电机空转时轻快不费劲。
- **易错**：先裁后装 → 带子短了接不上；绷太紧电机吃力、太松打滑跳齿。

### 第 14 步：装两个支架
- **用什么零件**：支架 2 个、M6 螺丝（拧进第 0 步商家攻好的端面螺纹孔）。
- **怎么做**：支架装到铝型材两端，M6 螺丝拧紧。
- **装好是什么样**：整根滑轨架起来放平，主机来回推动顺畅、不磕碰。

---

## 完工自检清单（全装完后带用户过一遍）

1. 控制板用的是塑料螺丝（不是金属）✔
2. 4 个轮子高度一致、转动顺畅 ✔
3. 云台在底座正中、拧紧 ✔
4. 两个限位开关接线颜色和排针对应正确 ✔
5. 电池魔术贴固定牢、扎带加固 ✔
6. 同步带绷紧适度、接头顶丝拧紧 ✔
7. 铝型材两端支架螺丝拧紧 ✔
8. 上电空跑一次：滑车能来回走、碰到限位开关能停/回头 ✔

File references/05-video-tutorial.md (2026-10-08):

# 05 · 演示视频与字幕时间轴（空降链接）

本文件用于：当用户想"看视频""看某一步具体怎么操作"或问到视频里讲过的细节时，给出**精准空降链接**，直接跳到对应画面。

## 视频地址

> https://www.bilibili.com/video/BV11MHQ65Eb9

标题：「我重生了！这一世我用 200 预算做出了电动滑轨【DIY 系列】」
简介处公布了改良后的滑轨资料与专门的 agent 提示词（即本技能包）。

## 空降链接格式

在视频地址后加 `?t=秒数` 即可跳到指定秒。秒数取对应字幕的**开始时间**（已换算好，保留一位小数）。

```
https://www.bilibili.com/video/BV11MHQ65Eb9?t=97.5
```

例：用户问"控制板为什么要用塑料螺丝" → 回 `?t=97.5`（视频 1:37 处讲短路烧板）；问"限位线怎么接" → 回 `?t=166.6`（蓝紫→最下排）和 `?t=168.7`（橙黄→上一排）。

## 一、常用问题 → 空降时间点（优先用这张表）

| 用户可能问 | 对应时间 | 空降链接 |
|---|---|---|
| 为什么做这台 / 预算多少 | 00:00:13 | [?t=13.8](https://www.bilibili.com/video/BV11MHQ65Eb9?t=13.8) |
| 参考了谁的方案 / 致谢原作者 | 00:00:32 | [?t=32.1](https://www.bilibili.com/video/BV11MHQ65Eb9?t=32.1) |
| agent 提示词怎么用（保姆级体验） | 00:00:43 | [?t=43.9](https://www.bilibili.com/video/BV11MHQ65Eb9?t=43.9) |
| 不到 200 元 / 有什么功能 | 00:00:53 | [?t=53.4](https://www.bilibili.com/video/BV11MHQ65Eb9?t=53.4) |
| 用 3D 打印替代亚克力（降本） | 00:01:04 | [?t=64.5](https://www.bilibili.com/video/BV11MHQ65Eb9?t=64.5) |
| 买铝型材让商家攻 M5/M6 丝 | 00:01:19 | [?t=79.1](https://www.bilibili.com/video/BV11MHQ65Eb9?t=79.1) |
| 电机 + 小板（M3×40）怎么固定 | 00:01:26 | [?t=86.3](https://www.bilibili.com/video/BV11MHQ65Eb9?t=86.3) |
| 控制板用 3D 打印 M3×8 螺丝（防短路） | 00:01:37 | [?t=97.5](https://www.bilibili.com/video/BV11MHQ65Eb9?t=97.5) |
| 没打印机用笔记本小螺丝替代 | 00:01:48 | [?t=108.4](https://www.bilibili.com/video/BV11MHQ65Eb9?t=108.4) |
| 同步轮装电机 | 00:01:52 | [?t=112.5](https://www.bilibili.com/video/BV11MHQ65Eb9?t=112.5) |
| 电机固定到底座（M3×8） | 00:01:57 | [?t=117.1](https://www.bilibili.com/video/BV11MHQ65Eb9?t=117.1) |
| 轮子 + 垫高圆锥 / 三颗 M5 螺母 | 00:02:07 | [?t=127.8](https://www.bilibili.com/video/BV11MHQ65Eb9?t=127.8) |
| 1/4 螺丝 + 云台 | 00:02:19 | [?t=139.0](https://www.bilibili.com/video/BV11MHQ65Eb9?t=139.0) |
| 限位开关杜邦线 + 带锡热缩管烧焊 | 00:02:27 | [?t=147.8](https://www.bilibili.com/video/BV11MHQ65Eb9?t=147.8) |
| 限位开关 M3 攻丝 + M3×12 固定 | 00:02:38 | [?t=158.5](https://www.bilibili.com/video/BV11MHQ65Eb9?t=158.5) |
| 限位接线：蓝紫→最下排 / 橙黄→上一排 | 00:02:46 | [?t=166.6](https://www.bilibili.com/video/BV11MHQ65Eb9?t=166.6) |
| 电池魔术贴可拆卸方案（本作改进点） | 00:02:56 | [?t=176.3](https://www.bilibili.com/video/BV11MHQ65Eb9?t=176.3) |
| 同步带先不裁 / T 型螺母固定 / 绷紧剪断 | 00:03:12 | [?t=192.5](https://www.bilibili.com/video/BV11MHQ65Eb9?t=192.5) |
| M6 螺丝装两个支架 / 完工 | 00:03:27 | [?t=207.3](https://www.bilibili.com/video/BV11MHQ65Eb9?t=207.3) |

## 二、完整字幕时间轴（清洗版，含空降链接）

> 说明：字幕为语音识别稿，已对明显听写错误做校正（如"旅行材"→铝型材、"三一打印"→3D 打印、"指令刷出打火机"→拿出打火机、"男子线"→蓝紫色线、"轮椅级"→保姆级）。时间点按原字幕开始时间换算。

1. [00:00:00](https://www.bilibili.com/video/BV11MHQ65Eb9?t=0.0) 当一台电动滑轨就能拍出这样的画面
2. [00:00:03](https://www.bilibili.com/video/BV11MHQ65Eb9?t=3.6) （开场白 / 背景铺垫）
3. [00:00:13](https://www.bilibili.com/video/BV11MHQ65Eb9?t=13.8) 鉴于市面上的电动滑轨价格都不太美丽
4. [00:00:16](https://www.bilibili.com/video/BV11MHQ65Eb9?t=16.6) 于是我们决定自己搓一台电动滑轨
5. [00:00:22](https://www.bilibili.com/video/BV11MHQ65Eb9?t=22.6) 经过一段时间的网络冲浪
6. [00:00:24](https://www.bilibili.com/video/BV11MHQ65Eb9?t=24.1) 我们发现大部分的方案要么制作难度高
7. [00:00:26](https://www.bilibili.com/video/BV11MHQ65Eb9?t=27.0) 要么难以理解
8. [00:00:28](https://www.bilibili.com/video/BV11MHQ65Eb9?t=28.2) （调侃 / 过渡，原稿听不清）
9. [00:00:30](https://www.bilibili.com/video/BV11MHQ65Eb9?t=30.2) （调侃台词）
10. [00:00:31](https://www.bilibili.com/video/BV11MHQ65Eb9?t=31.7) （停顿）
11. [00:00:32](https://www.bilibili.com/video/BV11MHQ65Eb9?t=32.1) 最终我们决定参考钟先生开源的那套制作方案
12. [00:00:35](https://www.bilibili.com/video/BV11MHQ65Eb9?t=35.5) 并对其进行了改进
13. [00:00:37](https://www.bilibili.com/video/BV11MHQ65Eb9?t=37.0) 在这里致敬钟先生的开源精神
14. [00:00:39](https://www.bilibili.com/video/BV11MHQ65Eb9?t=39.6) 我也会将改良后的滑轨资料完整开源
15. [00:00:42](https://www.bilibili.com/video/BV11MHQ65Eb9?t=42.3) 并公布在视频的简介处
16. [00:00:43](https://www.bilibili.com/video/BV11MHQ65Eb9?t=43.9) 并且我们提供了专门的 agent 提示词
17. [00:00:46](https://www.bilibili.com/video/BV11MHQ65Eb9?t=46.3) 只需要复制给 agent 就能获得保姆级的动手体验
18. [00:00:49](https://www.bilibili.com/video/BV11MHQ65Eb9?t=49.8) 是不是非常棒呢
19. [00:00:51](https://www.bilibili.com/video/BV11MHQ65Eb9?t=51.2) 现在呈现在你眼前的这台电动滑轨
20. [00:00:53](https://www.bilibili.com/video/BV11MHQ65Eb9?t=53.4) 是由我们团队花了不到 200 元手造出来的
21. [00:00:56](https://www.bilibili.com/video/BV11MHQ65Eb9?t=56.1) 它不仅支持终点停止、即走即停
22. [00:00:58](https://www.bilibili.com/video/BV11MHQ65Eb9?t=58.7) 调节速度
23. [00:00:59](https://www.bilibili.com/video/BV11MHQ65Eb9?t=59.6) 甚至是遥控控制
24. [00:01:01](https://www.bilibili.com/video/BV11MHQ65Eb9?t=61.0) 我们根据钟先生公开的 CAD 图纸进行建模
25. [00:01:04](https://www.bilibili.com/video/BV11MHQ65Eb9?t=64.5) 把原本需要定制的亚克力板
26. [00:01:06](https://www.bilibili.com/video/BV11MHQ65Eb9?t=66.3) 换成了更加容易获得的 3D 打印件
27. [00:01:08](https://www.bilibili.com/video/BV11MHQ65Eb9?t=68.8) 进一步降低了成本
28. [00:01:10](https://www.bilibili.com/video/BV11MHQ65Eb9?t=70.2) 也省去了快递等待的时间
29. [00:01:13](https://www.bilibili.com/video/BV11MHQ65Eb9?t=73.8) 接下来是组装教程
30. [00:01:15](https://www.bilibili.com/video/BV11MHQ65Eb9?t=75.5) 我将用最直白
31. [00:01:16](https://www.bilibili.com/video/BV11MHQ65Eb9?t=76.7) 最不绕弯子
32. [00:01:17](https://www.bilibili.com/video/BV11MHQ65Eb9?t=77.6) 在购买铝型材时
33. [00:01:19](https://www.bilibili.com/video/BV11MHQ65Eb9?t=79.1) 可以让商家在铝型材两端攻好 M5 或 M6 螺纹备用
34. [00:01:22](https://www.bilibili.com/video/BV11MHQ65Eb9?t=82.7) （螺纹备用，承上）
35. [00:01:23](https://www.bilibili.com/video/BV11MHQ65Eb9?t=83.9) 首先是电机部分的组装
36. [00:01:26](https://www.bilibili.com/video/BV11MHQ65Eb9?t=86.3) 拿出四颗 M3×40 螺丝
37. [00:01:28](https://www.bilibili.com/video/BV11MHQ65Eb9?t=88.9) 先套上螺母
38. [00:01:30](https://www.bilibili.com/video/BV11MHQ65Eb9?t=90.1) 用它把小板和电机固定在一起
39. [00:01:32](https://www.bilibili.com/video/BV11MHQ65Eb9?t=92.6) 在小板上我们也设计了四个圆柱
40. [00:01:35](https://www.bilibili.com/video/BV11MHQ65Eb9?t=95.2) 用于固定控制板
41. [00:01:36](https://www.bilibili.com/video/BV11MHQ65Eb9?t=96.7) 控制板
42. [00:01:37](https://www.bilibili.com/video/BV11MHQ65Eb9?t=97.5) 我们用了四颗 3D 打印的 M3×8 螺丝固定
43. [00:01:40](https://www.bilibili.com/video/BV11MHQ65Eb9?t=100.9) 选择 3D 打印螺丝
44. [00:01:42](https://www.bilibili.com/video/BV11MHQ65Eb9?t=102.5) 是因为之前用金属螺丝时出现过短路
45. [00:01:45](https://www.bilibili.com/video/BV11MHQ65Eb9?t=105.7) 烧板的现象
46. [00:01:46](https://www.bilibili.com/video/BV11MHQ65Eb9?t=106.9) 没有 3D 打印机的话
47. [00:01:48](https://www.bilibili.com/video/BV11MHQ65Eb9?t=108.4) 大家在这里使用笔记本的小螺丝
48. [00:01:50](https://www.bilibili.com/video/BV11MHQ65Eb9?t=110.5) 也可以（固定控制板）。接着取出同步轮
49. [00:01:52](https://www.bilibili.com/video/BV11MHQ65Eb9?t=112.5) 安装在电机上
50. [00:01:53](https://www.bilibili.com/video/BV11MHQ65Eb9?t=113.8) 拧好螺丝固定
51. [00:01:55](https://www.bilibili.com/video/BV11MHQ65Eb9?t=115.4) 然后在电机的另一边
52. [00:01:57](https://www.bilibili.com/video/BV11MHQ65Eb9?t=117.1) 用四颗 M3×8 螺丝把电机固定在底座上
53. [00:02:03](https://www.bilibili.com/video/BV11MHQ65Eb9?t=123.6) 接下来是轮子和云台部分的组装
54. [00:02:07](https://www.bilibili.com/video/BV11MHQ65Eb9?t=127.8) 首先把四颗 M5×30 螺丝安装在底座上
55. [00:02:10](https://www.bilibili.com/video/BV11MHQ65Eb9?t=130.3) 接下来四个螺丝放上垫高圆锥
56. [00:02:12](https://www.bilibili.com/video/BV11MHQ65Eb9?t=132.6) 或者用三颗 M5 螺母垫高
57. [00:02:13](https://www.bilibili.com/video/BV11MHQ65Eb9?t=133.9) 然后放上轮子
58. [00:02:16](https://www.bilibili.com/video/BV11MHQ65Eb9?t=136.5) 用钳子拧紧自锁螺母
59. [00:02:19](https://www.bilibili.com/video/BV11MHQ65Eb9?t=139.0) 下一步拿出 1/4 螺丝
60. [00:02:21](https://www.bilibili.com/video/BV11MHQ65Eb9?t=141.1) 放在底座中间的孔底下
61. [00:02:23](https://www.bilibili.com/video/BV11MHQ65Eb9?t=143.4) 紧接着把云台拧在螺丝上
62. [00:02:25](https://www.bilibili.com/video/BV11MHQ65Eb9?t=145.6) 再用六角螺丝把螺丝拧紧
63. [00:02:26](https://www.bilibili.com/video/BV11MHQ65Eb9?t=146.7) 完成上一步后
64. [00:02:27](https://www.bilibili.com/video/BV11MHQ65Eb9?t=147.8) 拿出杜邦线
65. [00:02:29](https://www.bilibili.com/video/BV11MHQ65Eb9?t=149.1) 穿过限位开关
66. [00:02:30](https://www.bilibili.com/video/BV11MHQ65Eb9?t=150.9) 再套上带锡热缩管
67. [00:02:32](https://www.bilibili.com/video/BV11MHQ65Eb9?t=152.6) 拿出打火机
68. [00:02:33](https://www.bilibili.com/video/BV11MHQ65Eb9?t=153.6) 烧化里面的锡
69. [00:02:34](https://www.bilibili.com/video/BV11MHQ65Eb9?t=154.8) 使其焊接好
70. [00:02:38](https://www.bilibili.com/video/BV11MHQ65Eb9?t=158.5) 接下来在限位开关上用 M3 丝锥攻好螺纹
71. [00:02:41](https://www.bilibili.com/video/BV11MHQ65Eb9?t=161.8) 再用 M3×12 的螺丝固定在底座上
72. [00:02:44](https://www.bilibili.com/video/BV11MHQ65Eb9?t=164.4) 然后把左边的限位开关的蓝紫色线
73. [00:02:46](https://www.bilibili.com/video/BV11MHQ65Eb9?t=166.6) 接在最下面的一排的排针上
74. [00:02:48](https://www.bilibili.com/video/BV11MHQ65Eb9?t=168.7) 右边的限位开关的橙黄色线
75. [00:02:50](https://www.bilibili.com/video/BV11MHQ65Eb9?t=170.6) 接在了紧挨着的上一排
76. [00:02:53](https://www.bilibili.com/video/BV11MHQ65Eb9?t=173.4) 接下来需要将电池固定在电机上
77. [00:02:56](https://www.bilibili.com/video/BV11MHQ65Eb9?t=176.3) 我们改进了原作者用扎带固定死的方案
78. [00:02:58](https://www.bilibili.com/video/BV11MHQ65Eb9?t=178.3) 改用了魔术贴可拆卸方案
79. [00:03:00](https://www.bilibili.com/video/BV11MHQ65Eb9?t=180.9) 将魔术贴贴在电池和电机上
80. [00:03:02](https://www.bilibili.com/video/BV11MHQ65Eb9?t=182.7) 为了防止背胶强度不够
81. [00:03:05](https://www.bilibili.com/video/BV11MHQ65Eb9?t=185.7) 可以进一步使用扎带把魔术贴固定住
82. [00:03:07](https://www.bilibili.com/video/BV11MHQ65Eb9?t=187.5) 这样电池就可以取下来
83. [00:03:09](https://www.bilibili.com/video/BV11MHQ65Eb9?t=189.0) 充电会更加方便
84. [00:03:10](https://www.bilibili.com/video/BV11MHQ65Eb9?t=190.9) 是不是很棒
85. [00:03:12](https://www.bilibili.com/video/BV11MHQ65Eb9?t=192.5) 最后同步带先不裁
86. [00:03:13](https://www.bilibili.com/video/BV11MHQ65Eb9?t=193.6) 在一头
87. [00:03:15](https://www.bilibili.com/video/BV11MHQ65Eb9?t=195.9) 用欧标 T 型螺母加 M5 顶丝
88. [00:03:17](https://www.bilibili.com/video/BV11MHQ65Eb9?t=197.5) 固定住同步带的一头
89. [00:03:18](https://www.bilibili.com/video/BV11MHQ65Eb9?t=199.0) 把主机滑入滑轨
90. [00:03:20](https://www.bilibili.com/video/BV11MHQ65Eb9?t=200.8) 穿过同步带绷紧后
91. [00:03:22](https://www.bilibili.com/video/BV11MHQ65Eb9?t=202.9) 另一头也用 T 型螺母固定
92. [00:03:23](https://www.bilibili.com/video/BV11MHQ65Eb9?t=204.0) 剪断同步带
93. [00:03:27](https://www.bilibili.com/video/BV11MHQ65Eb9?t=207.3) 最后再用 M6 螺丝装上滑轨的两个支架
94. [00:03:28](https://www.bilibili.com/video/BV11MHQ65Eb9?t=208.3) 大功告成
95. [00:03:30](https://www.bilibili.com/video/BV11MHQ65Eb9?t=210.5) 整套制作过程其实并不困难
96. [00:03:32](https://www.bilibili.com/video/BV11MHQ65Eb9?t=212.6) 手残党也能够轻松复刻
97. [00:03:34](https://www.bilibili.com/video/BV11MHQ65Eb9?t=214.7) 如果本期视频对你有所帮助
98. [00:03:36](https://www.bilibili.com/video/BV11MHQ65Eb9?t=216.5) 请留下一个大大的点赞
99. [00:03:38](https://www.bilibili.com/video/BV11MHQ65Eb9?t=218.1) 这会使我们更加有动力
100. [00:03:39](https://www.bilibili.com/video/BV11MHQ65Eb9?t=219.6) 创作更好的作品
101. [00:03:40](https://www.bilibili.com/video/BV11MHQ65Eb9?t=220.5) 我是（作者名）
102. [00:03:42](https://www.bilibili.com/video/BV11MHQ65Eb9?t=222.5) 我们下期视频再见

## 三、agent 使用方式

- 用户问"某一步具体怎么弄 / 想看视频 / 有演示吗"时，根据问题关键词在上表或时间轴中找到对应时间点，回复时**附上空降链接**。
- 一个回答可给 1-2 个最相关的时间点（例如限位接线给蓝紫、橙黄两条）。
- 秒数已换算好，直接拼 `?t=秒数` 即可，无需重新计算。
- 链接只用于辅助说明，**不能替代** references/03 的文字步骤与安全提醒。

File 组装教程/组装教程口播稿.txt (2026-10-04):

在购买铝型材时可以让商家在铝型材两端攻好M5或M6螺纹备用。

首先是电机部分的组装

拿出4颗M3×40螺丝先套上螺母，用它把小板和电机固定在一起；

在小板上我们也设计了 4 个圆柱用于固定控制板；

控制板我们用了 4 颗 3D 打印的 M3×8 螺丝固定；

选择3D打印螺丝是因为之前用金属螺丝时出现过短路烧板的现象。

没有3D打印机的话，大家在这里使用笔记本的小螺丝也可以。

接着，取出同步轮，安装到电机上，拧好螺丝固定。

然后在电机另一边用 4 颗 M3×8 螺丝，把电机固定在底座上。

接下来是轮子和云台部分的组装

首先把 4颗 M5×30 螺丝安装在底座上。

接下来4个螺丝放上垫高圆锥或者用3颗M5螺母垫高。

然后放上轮子，用钳子拧紧自锁螺母。

下一步拿出 1/4 螺丝，放在底座中间的孔底下。

紧接着把云台拧在螺丝上，再用六角螺丝刀把螺丝拧紧。

完成上一步后拿出杜邦线，穿过限位开关，再套上 带锡热缩管。

用指令刷出打火机烧化里面的锡使其焊接好。

接下来在限位开关上用 M3 丝锥攻好螺纹，再用 M3×12 螺丝固定在底座上。

然后把左边的限位开关的蓝紫线接在了最下面一排的排针上，

右边的限位开关的橙黄色线接在了紧挨着的上一排。

接下来需要将电池固定在电机上，我们改进了原作者用扎带固定死的方案。

改用魔术贴拆卸方案。将魔术贴贴在电池和电机上。为了防止背胶强度不够，可以进一步使用扎带把魔术贴固定住。这样电池就可以取下来，充电会更加方便。

最后同步带先不裁。在滑轨一头，用欧标 T 型螺母加 M5顶丝固定住同步带的一头；把主机滑入滑轨，穿过同步带，绷紧后，另一头也用 T 型螺母固定。剪断同步带

最后再用M6螺丝装上滑轨的两个支架，就大功告成了。

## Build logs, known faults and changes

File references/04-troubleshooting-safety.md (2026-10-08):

# 04 · 常见错误排查 + 安全注意事项

## 一、排错表（按"用户说现象 → 回答可能原因 → 给处理办法"使用）

### 电机 / 控制板类

| 现象 | 可能原因（按概率排序） | 处理办法 |
|---|---|---|
| 上电后控制板冒烟/烧了 | ①用金属螺丝固定控制板，顶到背面线路短路 | 立即断电。换 3D 打印塑料螺丝或笔记本小螺丝+绝缘垫片重新固定；板子大概率已损坏需更换 |
| 电机一点不动 | ①电池没电/没接好 ②驱动板接线松 ③遥控器没配对 | 先查电池 DC 头插紧没；再逐个按压驱动板上的接线端子；最后看套装说明书重新对码配对 |
| 电机嗡嗡响但不动 | ①同步带绷太紧 ②同步带没咬进同步轮齿里 | 松一点两端顶丝重新绷带；确认皮带齿对准轮齿卡进去 |
| 滑车走到头不停/撞端盖 | ①限位开关接线接反排 ②线头假焊（热缩管烧了但没焊牢） | 对照"蓝紫→最下一排、橙黄→上一排"重新插线；轻拽线头检查是否焊牢，假焊的重新烧一次 |
| 电机只在半程回头/提前停 | 限位开关翘板被刮到或位置装反 | 检查开关翘板朝向，调整到只有滑车能碰到 |

### 机械类

| 现象 | 可能原因 | 处理办法 |
|---|---|---|
| 轮子装完晃/车跑起来歪 | ①4 颗 M5×30 下面垫高不一致（圆锥数量不同或螺母数量不同）②自锁螺母没拧紧 | 统一每颗螺丝的垫高（要么全用圆锥、要么全串 3 颗 M5 螺母）；重新用钳子拧紧 |
| 轮子转不动 | 自锁螺母拧太死 | 松半圈，以"不晃、能拨动"为准 |
| 云台松动/拧不紧 | 1/4 螺丝没从底座孔下方穿、或没从下面用六角刀顶住拧紧 | 拆下重新装：螺丝从底座中间孔**下方**往上穿，云台拧上后从下面顶紧 |
| 螺丝拧不进铝型材孔 | 型材端面没攻丝 | 找商家补攻丝，或自己用 M5/M6 丝锥攻丝（参考下文安全区"攻丝"条） |
| 同步带打滑/跳齿（走的时候咔咔响） | 带子太松 | 松开一端顶丝，重新绷紧再固定 |
| 电机转着吃力/发烫 | 同步带绷太紧 | 适当放松，按下去有轻微弹性即可 |
| 同步带接头松脱 | T 型螺母没塞进槽里或顶丝没顶紧 | 确认 T 型螺母卡进型材凹槽、M5 顶丝压实带子 |
| 滑车推起来卡顿 | 轮子没卡进型材凹槽正中 | 把滑车抬起来重新对准凹槽放入 |
| 亚克力板孔位对不上 | 板的厚度/位置用错（4 块板厚度不同：8mm×2、5mm、3mm） | 按厚度重新分堆；对照图纸文件名核对每块用在哪 |

### 3D 打印 / 配件类

| 现象 | 可能原因 | 处理办法 |
|---|---|---|
| 没有 3D 打印螺丝固定控制板 | 没打印或没买打印件 | 用笔记本电脑小螺丝，或 M2 螺丝+绝缘垫片代替（必须是非导电方案） |
| 没有垫高圆锥 | 没打印 | 每颗 M5×30 螺丝串 3 颗 M5 普通螺母垫高（官方口播稿认可的替代方案） |
| 打印件孔太紧装不上 | 打印公差 | 用小刀轻修孔边毛刺，别硬砸 |

---

## 二、安全注意事项（凡涉及对应操作必须先说）

1. **打火机烧焊（第 9 步）**：只烧带锡热缩管、几秒即停；远离易燃物；烧完的接头烫，凉了再碰；烧过头会熔化线皮造成断线。
2. **攻丝（第 10 步）**：丝锥要对准孔、垂直旋入，边旋边倒半圈排屑；硬拧会断丝锥（断在里面很难取出，基本报废）。
3. **锂电池（第 12 步）**：不要短路两极、不要刺破外壳；充电用原装/配套充电器，人不要离岗；魔术贴（扎带加固）固定既防摔也方便取下充电。
4. **上电测试**：第一次通电前再过一遍接线颜色（蓝紫→最下排、橙黄→上一排）；手指远离同步轮和同步带，电机运转时不要伸手入轨。
5. **裁剪同步带**：绷紧状态下裁剪时刀口朝外，避免割手；裁完马上给切口修齐。
6. **钳子使用**：夹自锁螺母时手指不要放在钳口与螺母之间。

## 三、回答时的补充规则

- 用户描述的现象不在表里时：让用户拍下/描述"哪一步、装到什么程度、出现什么声音或现象"，再按最接近的条目推断，并明确说"这是最可能的原因"。
- 涉及烧板、断丝锥这类不可逆损失，回答里要给出"如何避免再次发生"的一句提醒。
- 用户问"我这样装对不对"时，让用户对照 03 号文件末尾的"完工自检清单"逐条核对。

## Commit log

2026-10-04 Initial commit: DIY electric acrylic camera slider - drawings, 3D print files, parts list and assembly guide
    [3d模型_M3螺丝x10.3mf, 3d模型_滑轨所需模型.3mf, 导轨材料清单.xlsx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]
2026-10-06 docs: 明确定制范围——仅亚克力需定制，有3D打印机可自打印替代；铝材攻丝M5/M6均可
2026-10-06 docs: 移除3D打印代工选项，板件改为二选一——有打印机自打/无打印机定制亚克力
2026-10-06 docs: 同步材料清单改名与更新内容——电动滑轨材料清单.xlsx；导轨/热缩管/扎带/M5或M6螺丝12mm 等
    [导轨材料清单.xlsx, 电动滑轨材料清单.xlsx]
2026-10-08 docs: 加入B站演示视频链接与带时间戳字幕索引(references/05)，电池固定对齐视频魔术贴方案
2026-10-09 docs: 微调README演示视频说明段落，收紧电池固定方案措辞
